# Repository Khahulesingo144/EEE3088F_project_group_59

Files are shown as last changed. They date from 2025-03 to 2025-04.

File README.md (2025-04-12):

# EEE3088F 2025 Micro-Mouse Power Subsystem

## Overview
This repository contains all design files and documentation for the power subsystem of the Micro-Mouse project, as part of the EEE3088F 2025 course at the University of Cape Town. 

The power module is responsible for delivering regulated power to the entire micro-mouse system, supporting motor driving, USB-C power input, battery monitoring and charging, and high-side switching for external loads.

## Project Objectives
- Design and manufacture a power PCB that:
  - Powers 4 motors (2x 200mA and 2x 500mA brushed DC)
  - Charges a LiPo battery from a 9V USB-C input (with 200mA and ~600mA charge modes)
  - Integrates an INA219 sensor for battery voltage/current monitoring
  - Supplies 5V @ 1.5A and 3.3V @ 300mA regulated outputs
  - Supports dual high-side external load switching (1A each)
  - Includes ON/OFF switching (<30μA off-state draw, 2A on-state peak)
- Stay within the strict $70 budget for manufacturing and components
- Ensure physical compatibility with the provided micro-mouse motherboard

## Tools Used
- **KiCad** – Schematic capture and PCB layout
- **JLCPCB** – PCB manufacturing and assembly
- **Git** – Version control
- **LaTeX** – Report writing

## Key Files
- `jlcpcb/production_files/GERBER-EEE3088F_2025_Project.zip` – Final Gerber files for PCB manufacturing
- `jlcpcb/production_files/BOM-EEE3088F_2025_Project.csv` – Bill of Materials for JLCPCB
- `jlcpcb/production_files/CPL-EEE3088F_2025_Project.csv` – Pick and Place file for assembly

## Contributors
- **Student 1**: Khahule Singo, Student Number: SNGKHA008
- **Student 2**: Otsile Diale, Student Number: DLXOTS001

Each student is responsible for distinct sections of the design and has submitted an individual report accordingly.

## License
This repository is intended for academic use only. Please do not reproduce or redistribute without permission.

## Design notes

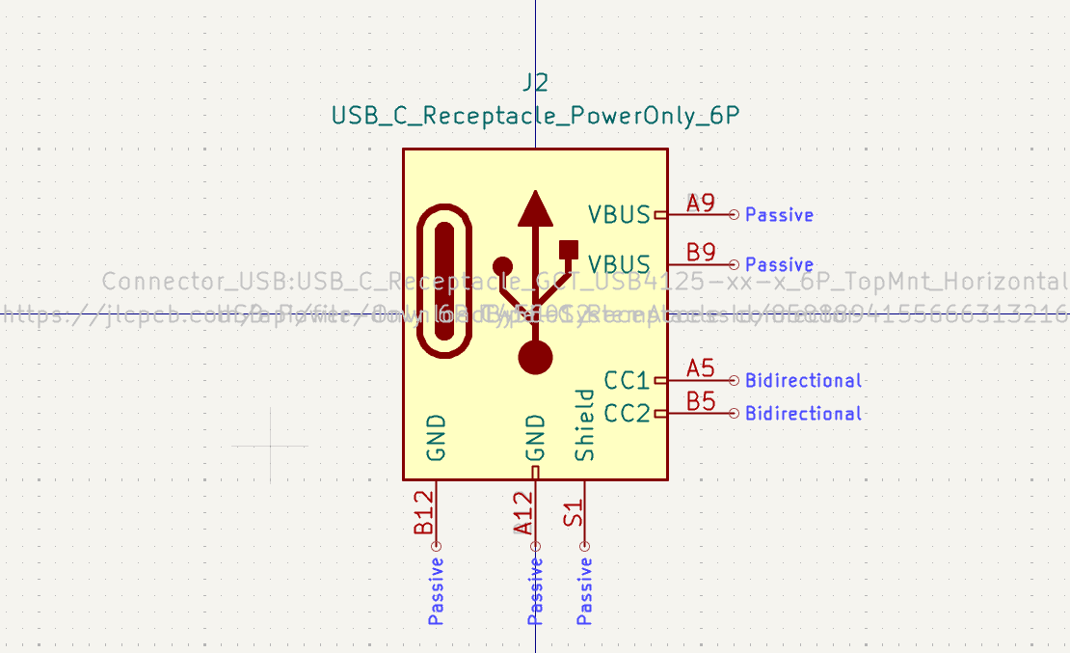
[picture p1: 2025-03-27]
USB_C_Receptacle_PowerOnly_6P.png

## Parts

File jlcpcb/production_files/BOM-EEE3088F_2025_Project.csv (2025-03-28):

Comment | Designator | Footprint | LCSC | Quantity
AP2171WG-7 | U11,U7 | SOT-25-5_L2.9-W1.6-P0.95-LS2.8-BL | C110466 | 2
HR8833 | U1,U2 | TSSOP-16_4.4x5mm_P0.65mm | C128666 | 2
0.1u | C16 | C_0201_0603Metric_Pad0.64x0.40mm_HandSolder | C1525 | 1
10u | C1,C5,C7,C8 | C_0805_2012Metric_Pad1.18x1.45mm_HandSolder | C15850 | 4
TP4056-42-ESOP8 | U8 | SOIC-8-1EP_3.9x4.9mm_P1.27mm_EP2.41x3.3mm_ThermalVias | C16581 | 1
0.01u | C3,C4 | C_0805_2012Metric_Pad1.18x1.45mm_HandSolder | C1710 | 2
5R1 | R11 | R_0805_2012Metric_Pad1.20x1.40mm_HandSolder | C17724 | 1
10K | R15,R16 | R1206 | C17902 | 2
1R | R1,R2 | R1206 | C17928 | 2
120pF | C13 | C_0805_2012Metric_Pad1.18x1.45mm_HandSolder | C18438 | 1
0.39R | R3,R4 | R1206 | C188072 | 2
TPS613222ADBVR | U5 | SOT-23-5 | C2071163 | 1
CJ78L05 | U9 | SOT-89-3 | C2079 | 1
NMOS | Q2 | SOT-23-3 | C20917 | 1
1K | R5,R6 | R_0201_0603Metric_Pad0.64x0.40mm_HandSolder | C21190 | 2
HUSB237-AA001-DN06R | U6 | DFN-6-1EP_2x2mm_P0.65mm_EP1.01x1.7mm | C22373734 | 1
LED | D1 | LED_0201_0603Metric_Pad0.64x0.40mm_HandSolder | C2286 | 1
LED | D3 | LED_0201_0603Metric_Pad0.64x0.40mm_HandSolder | C2290 | 1
75K | R7 | R_0603_1608Metric_Pad0.98x0.95mm_HandSolder | C23242 | 1
1uF | C12,C14,C17 | C_0805_2012Metric_Pad1.18x1.45mm_HandSolder | C28323 | 3
2.2u | C2,C6 | C_0805_2012Metric_Pad1.18x1.45mm_HandSolder | C377773 | 2
1.8K | R8 | R_0201_0603Metric_Pad0.64x0.40mm_HandSolder | C4177 | 1
SW_SPDT | SW1 | SW_Slide_SPDT_Angled_CK_OS102011MA1Q | C431541 | 1
5.5K | R12 | R_0201_0603Metric_Pad0.64x0.40mm_HandSolder | C4382 | 1
USB_C_Receptacle_PowerOnly_6P | J2 | USB_C_Receptacle_GCT_USB4125-xx-x_6P_TopMnt_Horizontal | C456012 | 1
22uF | C11 | C_0805_2012Metric_Pad1.18x1.45mm_HandSolder | C45783 | 1
AP2112K-3.3 | U4 | SOT-25-5_L2.9-W1.6-P0.95-LS2.8-BL | C51118 | 1
0.33u | C15 | C_0201_0603Metric_Pad0.64x0.40mm_HandSolder | C5139492 | 1
3m | R9 | R2512 | C5375459 | 1
2.2uH | L1 | L_1008_2520Metric_Pad1.43x2.20mm_HandSolder | C86092 | 1
SS34 | D2 | D_SMA | C8678 | 1
INA219AIDCNR | U10 | SOT-23-8_Handsoldering | C87469 | 1

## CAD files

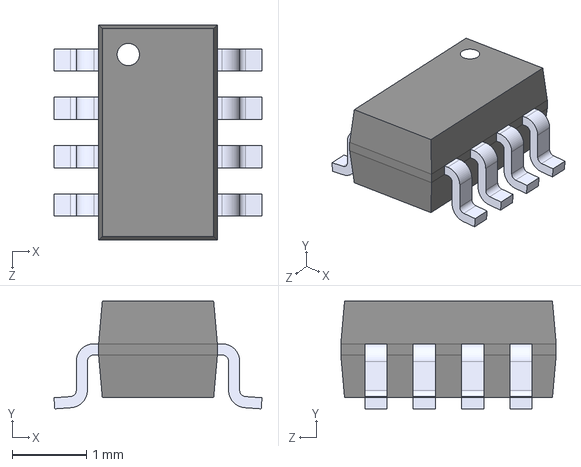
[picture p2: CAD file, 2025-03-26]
INA219AIDCNR.step
2.80 x 1.45 x 2.90 mm

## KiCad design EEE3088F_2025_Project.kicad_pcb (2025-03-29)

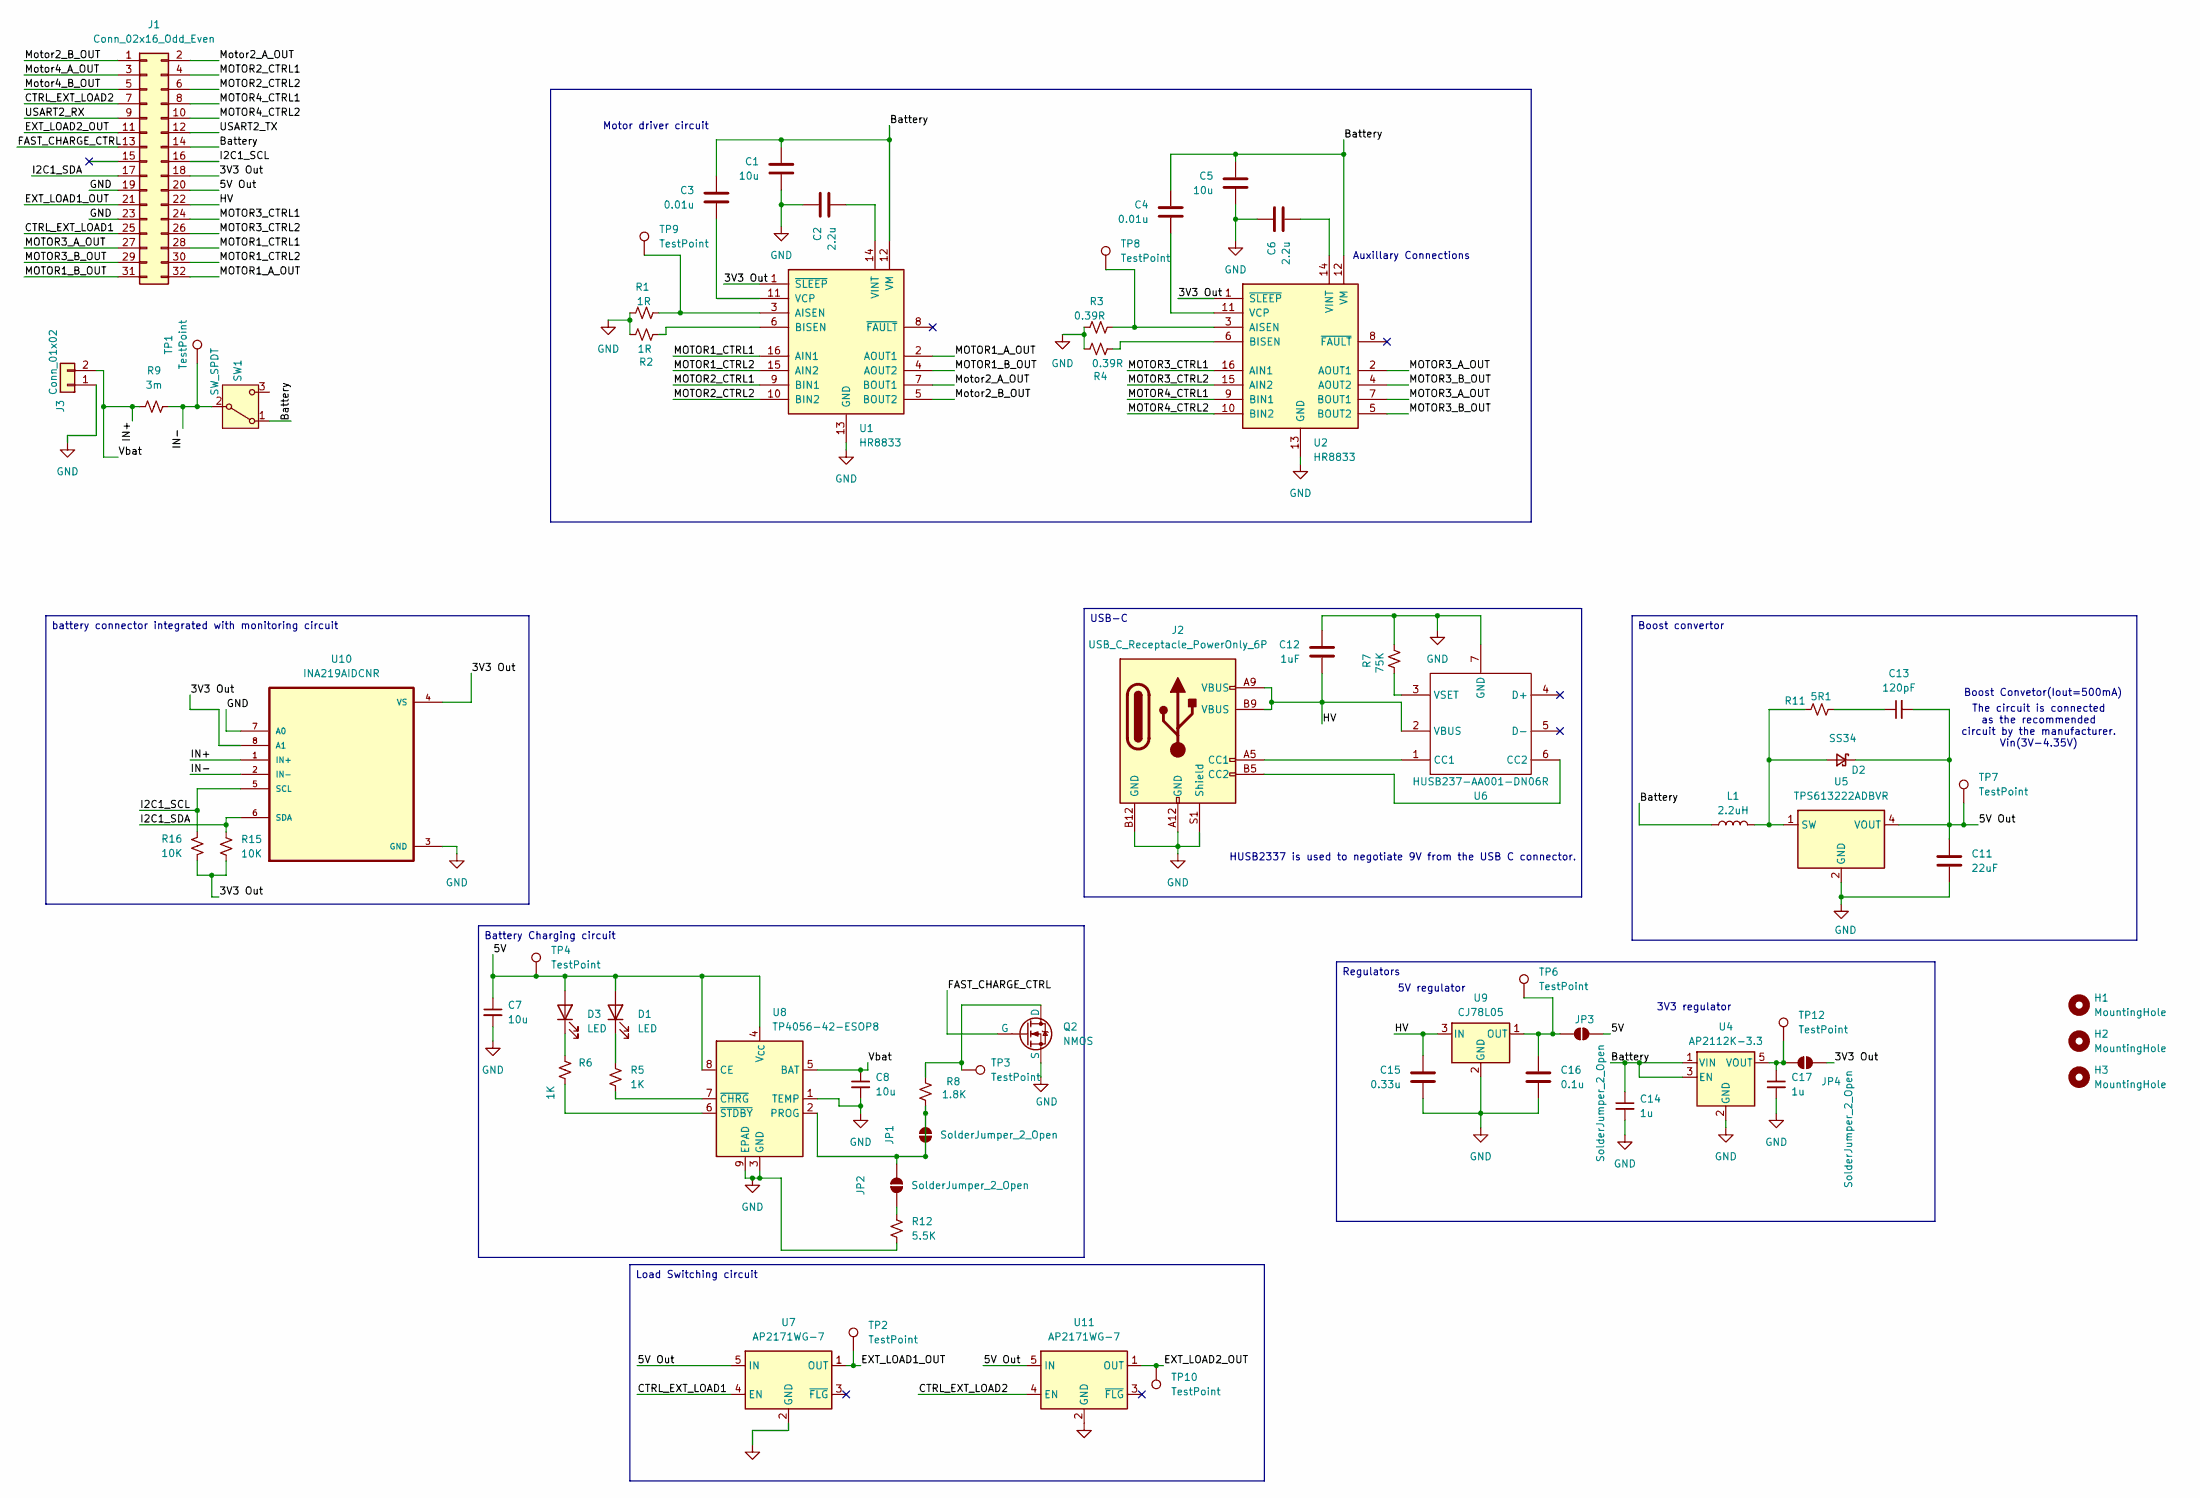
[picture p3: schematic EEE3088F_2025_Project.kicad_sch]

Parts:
C1, C5, C7, C8: 10u; C_0805_2012Metric_Pad1.18x1.45mm_HandSolder
C2, C6: 2.2u; C_0805_2012Metric_Pad1.18x1.45mm_HandSolder; LCSC C377773
C3, C4: 0.01u; C_0805_2012Metric_Pad1.18x1.45mm_HandSolder; LCSC C1710
C11: 22uF; C_0805_2012Metric_Pad1.18x1.45mm_HandSolder
C12: 1uF; C_0805_2012Metric_Pad1.18x1.45mm_HandSolder
C13: 120pF; C_0805_2012Metric_Pad1.18x1.45mm_HandSolder; LCSC C18438
C14: 1u; C_0805_2012Metric_Pad1.18x1.45mm_HandSolder
C15: 0.33u; C_0201_0603Metric_Pad0.64x0.40mm_HandSolder; LCSC C5139492
C16: 0.1u; C_0201_0603Metric_Pad0.64x0.40mm_HandSolder; LCSC C1525
C17: 1u; C_0805_2012Metric_Pad1.18x1.45mm_HandSolder; LCSC C28323
D1, D3: LED; LED_0201_0603Metric_Pad0.64x0.40mm_HandSolder
D2: SS34; D_SMA; LCSC C8678
H1, H2, H3: MountingHole; MountingHole_3.2mm_M3_DIN965_Pad
J1: Conn_02x16_Odd_Even; PinHeader_2x16_P2.54mm_Vertical
J2: USB_C_Receptacle_PowerOnly_6P; USB_C_Receptacle_GCT_USB4125-xx-x_6P_TopMnt_Horizontal; LCSC C456012
J3: Conn_01x02; JST_PH_S2B-PH-K_1x02_P2.00mm_Horizontal; LCSC C541760
JP1, JP2, JP3, JP4: SolderJumper_2_Open; SolderJumper-2_P1.3mm_Open_Pad1.0x1.5mm
L1: 2.2uH; L_1008_2520Metric_Pad1.43x2.20mm_HandSolder; LCSC C86092
Q2: NMOS; SOT-23-3; LCSC C20917
R1, R2: 1R; R1206; LCSC C17928
R3, R4: 0.39R; R1206; LCSC C188072
R5, R6: 1K; R_0201_0603Metric_Pad0.64x0.40mm_HandSolder
R7: 75K; R_0603_1608Metric_Pad0.98x0.95mm_HandSolder; LCSC C23242
R8: 1.8K; R_0201_0603Metric_Pad0.64x0.40mm_HandSolder; LCSC C4177
R9: 3m; R2512; LCSC C5375459
R11: 5R1; R_0805_2012Metric_Pad1.20x1.40mm_HandSolder; LCSC C17724
R12: 5.5K; R_0201_0603Metric_Pad0.64x0.40mm_HandSolder; LCSC C4382
R15, R16: 10K; R1206
SW1: SW_SPDT; SW_Slide_SPDT_Angled_CK_OS102011MA1Q; LCSC C431548
TP1, TP2, TP3, TP4, TP6, TP7, TP8, TP9, TP10, TP12: TestPoint; TestPoint_THTPad_D2.0mm_Drill1.0mm
U1, U2: HR8833; TSSOP-16_4.4x5mm_P0.65mm; LCSC C128666
U4: AP2112K-3.3; SOT-25-5_L2.9-W1.6-P0.95-LS2.8-BL; LCSC C51118
U5: TPS613222ADBVR; SOT-23-5; LCSC C2071163
U6: HUSB237-AA001-DN06R; DFN-6-1EP_2x2mm_P0.65mm_EP1.01x1.7mm; LCSC C22373734
U7, U11: AP2171WG-7; SOT-25-5_L2.9-W1.6-P0.95-LS2.8-BL; LCSC C110466
U8: TP4056-42-ESOP8; SOIC-8-1EP_3.9x4.9mm_P1.27mm_EP2.41x3.3mm_ThermalVias; LCSC C16581
U9: CJ78L05; SOT-89-3; LCSC C2079
U10: INA219AIDCNR; SOT-23-8_Handsoldering; LCSC C87469

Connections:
/3V3 Out: J1.18, JP4.1 (A), R15.2, R16.2, U1.1 (~SLEEP), U2.1 (~SLEEP), U10.4 (VS), U10.8 (A1)
/5V: C7.1, D1.2 (A), D3.2 (A), JP3.1 (A), TP4.1, U8.4 (V_{CC}), U8.8 (CE)
/5V Out: C11.1, C13.2, D2.1 (K), J1.20, TP7.1, U5.4 (VOUT), U7.5 (IN), U11.5 (IN)
/Battery: C1.1, C3.1, C4.1, C5.1, C14.1, J1.14, L1.1, SW1.1 (A), U1.12 (VM), U2.12 (VM), U4.1 (VIN), U4.3 (EN)
/CTRL_EXT_LOAD1: J1.25, U7.4 (EN)
/CTRL_EXT_LOAD2: J1.7, U11.4 (EN)
/EXT_LOAD1_OUT: J1.21, TP2.1, U7.1 (OUT)
/EXT_LOAD2_OUT: J1.11, TP10.1, U11.1 (OUT)
/FAST_CHARGE_CTRL: J1.13, Q2.2 (G)
/HV: C12.2, C15.1, J1.22, J2.A9 (VBUS), J2.B9 (VBUS), U6.2 (VBUS), U9.3 (IN)
/I2C1_SCL: J1.16, R16.1, U10.5 (SCL)
/I2C1_SDA: J1.17, R15.1, U10.6 (SDA)
/IN+: C8.1, J3.2, R9.1, U8.5 (BAT), U10.1 (IN+)
/IN-: R9.2, SW1.2 (B), TP1.1, U10.2 (IN-)
/MOTOR1_A_OUT: J1.32, U1.2 (AOUT1)
/MOTOR1_B_OUT: J1.31, U1.4 (AOUT2)
/MOTOR1_CTRL1: J1.28, U1.16 (AIN1)
/MOTOR1_CTRL2: J1.30, U1.15 (AIN2)
/MOTOR2_CTRL1: J1.4, U1.9 (BIN1)
/MOTOR2_CTRL2: J1.6, U1.10 (BIN2)
/MOTOR3_A_OUT: J1.27, U2.2 (AOUT1), U2.7 (BOUT1)
/MOTOR3_B_OUT: J1.29, U2.4 (AOUT2), U2.5 (BOUT2)
/MOTOR3_CTRL1: J1.24, U2.16 (AIN1)
/MOTOR3_CTRL2: J1.26, U2.15 (AIN2)
/MOTOR4_CTRL1: J1.8, U2.9 (BIN1)
/MOTOR4_CTRL2: J1.10, U2.10 (BIN2)
/Motor2_A_OUT: J1.2, U1.7 (BOUT1)
/Motor2_B_OUT: J1.1, U1.5 (BOUT2)
/Motor4_A_OUT: J1.3
/Motor4_B_OUT: J1.5
/USART2_RX: J1.9
/USART2_TX: J1.12
GND: C1.2, C2.1, C5.2, C6.1, C7.2, C8.2, C11.2, C12.1, C14.2, C15.2, C16.2, C17.2, H1.1, H2.1, H3.1, J1.19, J1.23, J2.A12 (GND), J2.B12 (GND), J2.S1 (Shield), J3.1, Q2.3 (S), R1.1, R2.1, R3.1, R4.1, R7.1, R12.2, U1.13 (GND), U2.13 (GND), U4.2 (GND), U5.2 (GND), U6.7 (GND), U7.2 (GND), U8.1 (TEMP), U8.3 (GND), U8.9 (EPAD), U9.2 (GND), U10.3 (GND), U10.7 (A0), U11.2 (GND)
unnamed: C13.1, R11.2
unnamed: D1.1 (K), R5.1
unnamed: D2.2 (A), L1.2, R11.1, U5.1 (SW)
unnamed: D3.1 (K), R6.1
unnamed: J2.A5 (CC1), U6.1 (CC1)
unnamed: J2.B5 (CC2), U6.6 (CC2)
unnamed: JP1.1 (A), JP1.2 (B), JP2.2 (B), R8.2, U8.2 (PROG)
unnamed: JP2.1 (A), R12.1
unnamed: C16.1, JP3.2 (B), TP6.1, U9.1 (OUT)
unnamed: C17.1, JP4.2 (B), TP12.1, U4.5 (VOUT)
unnamed: Q2.1 (D), R8.1, TP3.1
unnamed: R1.2, TP9.1, U1.3 (AISEN)
unnamed: R2.2, U1.6 (BISEN)
unnamed: C3.2, U1.11 (VCP)
unnamed: C2.2, U1.14 (VINT)
unnamed: R3.2, TP8.1, U2.3 (AISEN)
unnamed: R4.2, U2.6 (BISEN)
unnamed: C4.2, U2.11 (VCP)
unnamed: C6.2, U2.14 (VINT)
unnamed: R7.2, U6.3 (VSET)
unnamed: R5.2, U8.7 (~CHRG)
unnamed: R6.2, U8.6 (~STDBY)

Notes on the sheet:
HUSB2337 is used to negotiate 9V from the USB C connector.
5V regulator
Auxillary Connections
Boost Convetor(Iout=500mA)
3V3 regulator
The circuit is connected as the recommended circuit by the manufacturer. Vin(3V-4.35V)
Motor driver circuit
Load Switching circuit
Battery Charging circuit
USB-C
battery connector integrated with monitoring circuit
Regulators
Boost convertor

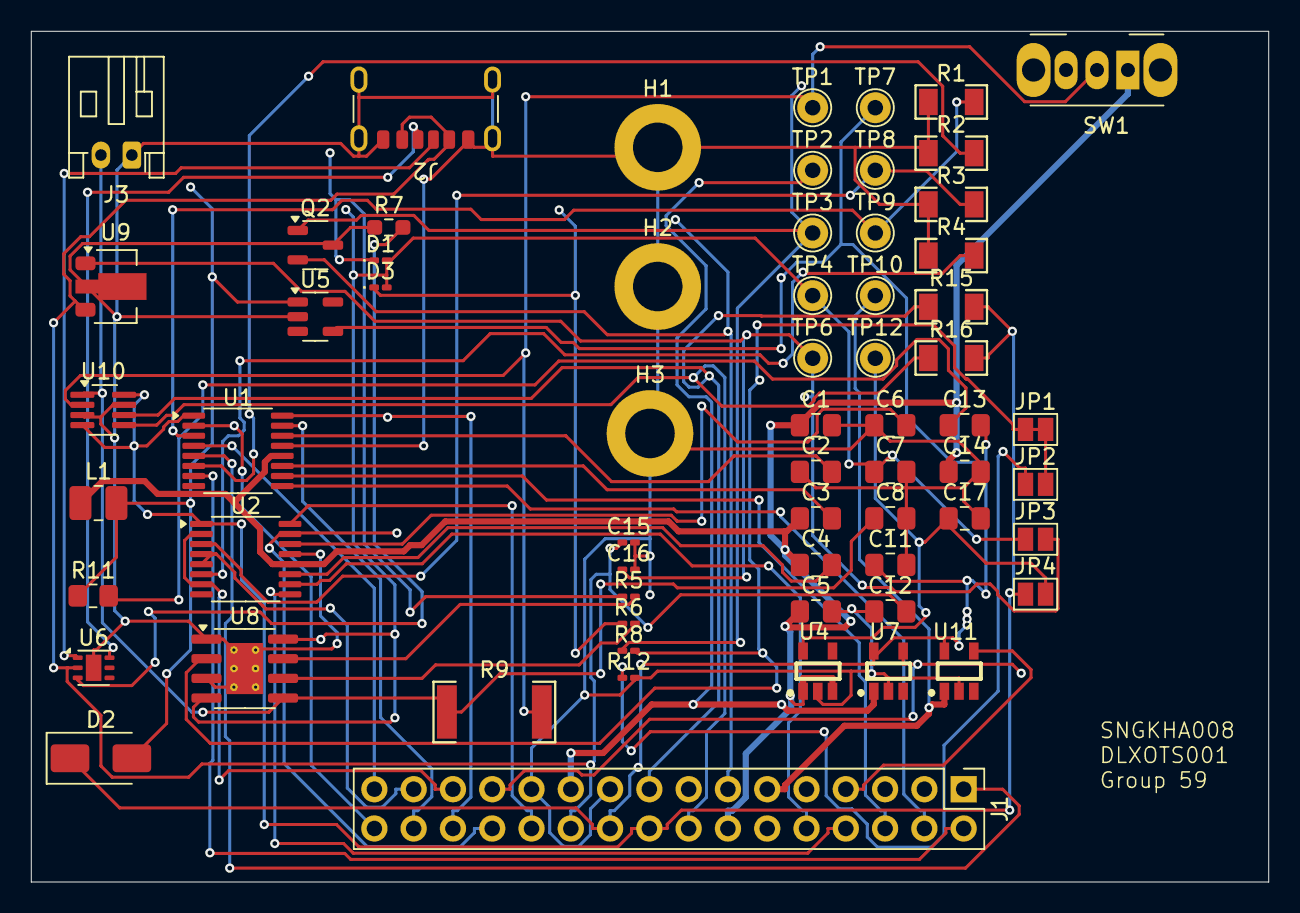
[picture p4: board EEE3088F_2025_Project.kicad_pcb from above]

Board: 2 copper layers, 80.0 x 55.0 mm, 64 parts (0 on the bottom side), 51 nets.

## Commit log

2025-03-20 Add files via upload
    Created a file to be edited to create the project schematic
2025-03-20 Add files via upload
    Added Kicad schematic file to be used for the project
    [EEE3088F_2025_Project.kicad_sch]
2025-03-20 added dummy component to test commit
    [EEE3088F_2025_Project.kicad_sch]
2025-03-20 added other file and backups
    [EEE3088F_2025_Project.kicad_pcb]
2025-03-21 Addded motor drivers and connector
    [EEE3088F_2025_Project.kicad_sch]
2025-03-22 Added dummy charging IC, struggling to add JLCPCB to Kicad
    [EEE3088F_2025_Project.kicad_sch]
2025-03-22 made minor changes to labels
    [EEE3088F_2025_Project.kicad_sch]
2025-03-22 Added INA219
    [EEE3088F_2025_Project.kicad_sch]
2025-03-22 Added a switch, 3V3 and 5V out, intergrated USB C
    [EEE3088F_2025_Project.kicad_sch]
2025-03-24 added footprint for usb c connector
    [EEE3088F_2025_Project.kicad_sch]
2025-03-24 Added INA219, status LEDs for charging
    [EEE3088F_2025_Project.kicad_sch]
2025-03-24 Change charging IC to have 5 pins
    [EEE3088F_2025_Project.kicad_sch]
2025-03-25 Adjusted the boost conv to get 500mA
    [EEE3088F_2025_Project.kicad_pcb, EEE3088F_2025_Project.kicad_sch]
2025-03-25 Added footprints and LCSC numbers
    [EEE3088F_2025_Project.kicad_pcb, EEE3088F_2025_Project.kicad_sch]
2025-03-26 Added lcsc number for resistors and capacitors
    [EEE3088F_2025_Project.kicad_sch]
2025-03-26 Changed charging IC
    [EEE3088F_2025_Project.kicad_sch]
2025-03-26 Added new footprint for 1*2 connector
    [EEE3088F_2025_Project.kicad_sch, freerouting.dsn, temp-freerouting.dsn]
2025-03-26 Changed the configuration for INA219
    [EEE3088F_2025_Project.kicad_sch, INA219AIDCNR.step]
2025-03-26 Added LCSC numbers and changed switch to SPDT
    [EEE3088F_2025_Project.kicad_sch]
2025-03-26 fixed footprint for SW1 to be vertical pin
    [EEE3088F_2025_Project.kicad_sch]
2025-03-27 Changed regulator and NMOS footprint
    [EEE3088F_2025_Project.kicad_sch]
2025-03-27 Added edge cuts
    [-CuBottom.gbr, -CuTop.gbr, -EdgeCuts.gbr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]
2025-03-27 Added testpoints and board layout shape
    [EEE3088F_2025_Project.kicad_pcb, EEE3088F_2025_Project.kicad_sch, freerouting.dsn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]
2025-03-27 Added B.Cu layer as ground plane
    [EEE3088F_2025_Project.kicad_pcb]
2025-03-27 Added mounting holes
    [EEE3088F_2025_Project.kicad_pcb, EEE3088F_2025_Project.kicad_sch]
2025-03-28 Added mounting holes and solder jumpers
    [-CuBottom.gbr, -CuTop.gbr, -EdgeCuts.gbr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]
2025-03-28 added routing
    [BOM-EEE3088F_2025_Project.csv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]
2025-03-29 Final files used for submission
    [CPL-EEE3088F_2025_Project.csv, EEE3088F_2025_Project-CuBottom.gbr, EEE3088F_2025_Project-CuTop.gbr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]
